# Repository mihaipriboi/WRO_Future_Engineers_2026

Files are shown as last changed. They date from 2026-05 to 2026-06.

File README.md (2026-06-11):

<center><h1> Nerdvana Cancer 2026 </center>

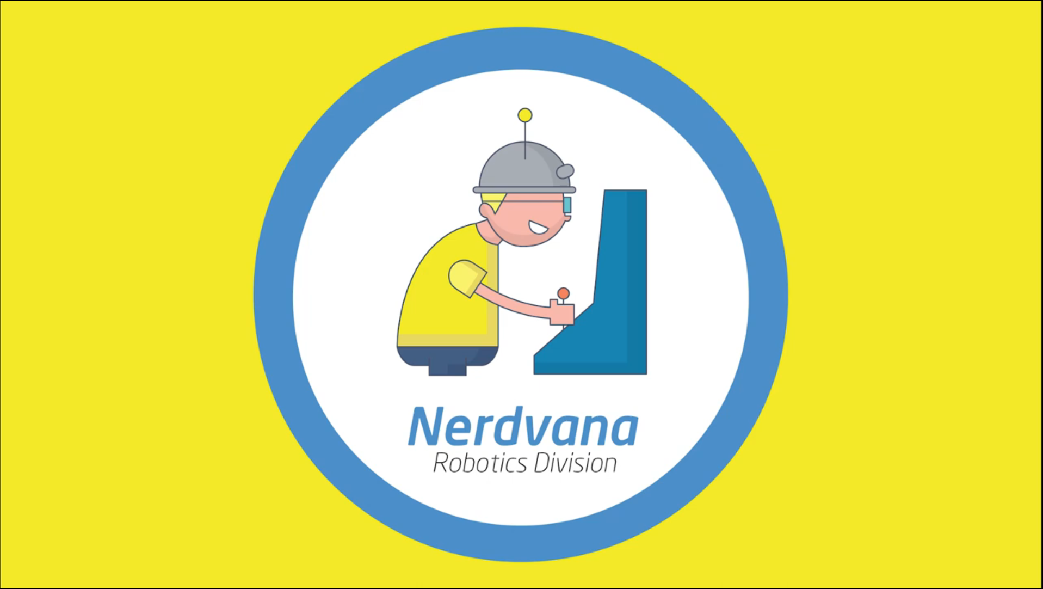
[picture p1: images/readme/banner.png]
Banner




This repository contains the documentation for the Nerdvana Cancer team's robot for the 2026 World Robot Olympiad Future Engineers competition. The robot, was designed and built by a team of three students.

## Table of Contents
* [The Team](#team)
* [The Challenge](#challenge)
* [The Robot](#robot-image)
* [Performance Video](#video)
* [The Team's Evolution Over the Years](#team-evolution)
  * [2022 Paula (Pretty Awesome Ultra Low Accurate robot) - International (Germany) - 8th Place](#2022-international)
  * [2023 Paula Mia (Pretty Awesome Ultra Low Accurate Minimum Intelligence Augmentation) - National - 1st Place](#2023-national)
  * [2023 Paula Mia 2 (Pretty Awesome Ultra Locomotion Autonomous Mapping Intelligence Augmentation) - International (Panama) - 17th Place](#2023-international)
  * [2024 TBD - National - 1st Place](#2024-national)
  * [2024 MOOYA (Mechanized Optimization for Outstanding Yield and Adaptation) - International (Turkey) - 7th Place](#2024-international)
  * [2025 MOOYA* (Mechanized Optimization for Outstanding Yield and Adaptation) - National - 1st Place](#2025-national)
  * [2025 L.A.C.H.E. (Lightweight Autonomous Carbon-Hybrid Entity) - International](#2025-international)
  * [2026 M.D.S (Memory, Dead-reckoning & Steering) - Current Robot](#2026-current)
* [Mobility Management](#mobility-management)
  * [Powertrain](#powertrain-mechanical)
    * [Drivetrain](#drivetrain-mechanical)
    * [Motor](#motor-mechanical)
    * [Motor Driver](#motor-driver-mechanical)
  * [Steering](#steering-mechanical)
    * [Servo Motor](#servo-motor)
  * [Chassis](#chassis-mechanical)
* [Power and Sense Management](#power-and-sense-management)
  * [Li-Po Battery](#li-po-battery)
  * [Arduino Nano ESP32](#arduino-nano-esp32)
  * [IMU](#imu-sensor)
  * [OpenMV Cam H7 R2](#openmv-cam-rt1062)
  * [Voltage Regulator](#voltage-regulator)
  * [PCB Design](#pcb)
  * [Circuit Diagram](#circuit-diagram)
* [Code for each component](#code-for-each-component)
  * [Drive Motor](#drive-motor-code)
  * [Servo Motor](#servo-motor-code)
  * [Camera](#camera-code)
  * [IMU](#gyro-sensor-code)
* [Obstacle Management](#obstacle-management)
  * [Qualification Round](#quali-management)
  * [Final Round](#final-management)
  * [Additional code](#additional-code)
* [What We Changed This Year](#whats-new)
  * [Tuning and telemetry over WiFi](#wifi-dashboard)
  * [A drift-free gyro that finds its own straight](#self-straight)
  * [Our own localization and route memory](#self-localization)
  * [Rethinking the parking](#smart-parking)
  * [Where this is heading](#next-steps)
* [Robot Construction Guide](#robot-construction-guide)
  * [Step 0: Print the 3D parts](#3d-printing)
  * [Step 1: Assemble the steering system](#steering-system-assembly)
  * [Step 2: Assemble the powertrain](#powertrain-assembly)
  * [Step 3: Attach the electronics](#electronics-attachment)
  * [Step 4: Upload the code](#code-upload)
* [Cost Report](#cost-report)
  * [3D Printing Costs](#3d-printing-costs)
  * [Other Parts Tested](#other-parts-tested)
  * [Tools and Equipment](#tools-and-equipment)
  * [Summary of Costs](#summary-of-costs)
* [Randomizer](#randomizer)
* [Resources](#resources)
  * [3D Models](#3d-models-resources)
  * [Images](#images-resources)
* [License](#copyright)

---

## The Team 

### Priboi Luca Mihai
<p align="center">
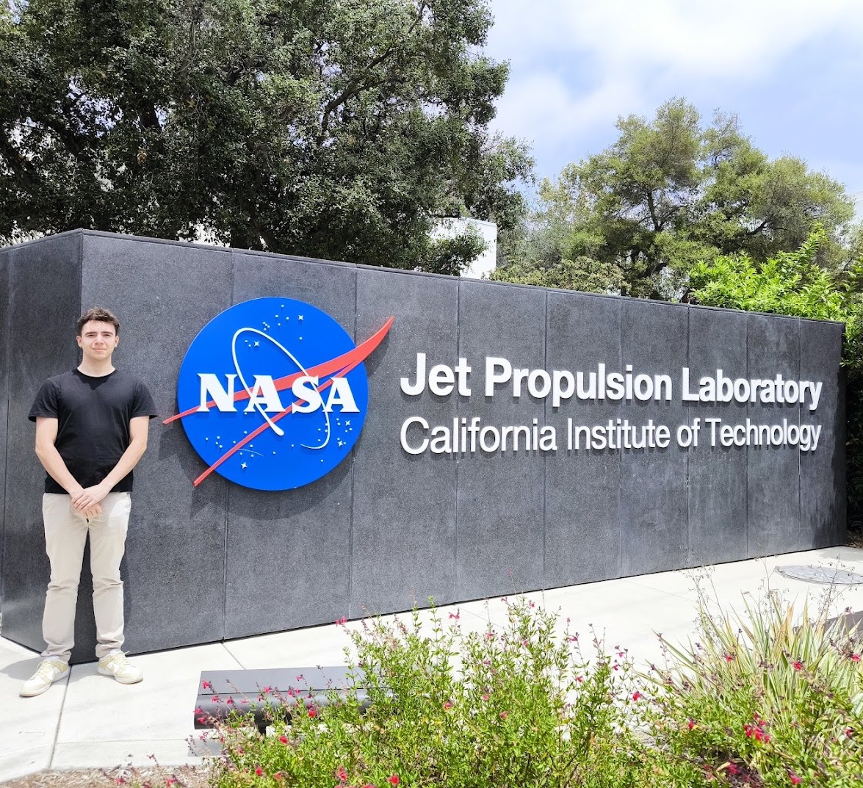
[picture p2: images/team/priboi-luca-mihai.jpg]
Priboi Luca Mihai
  
</p>

<b>Age:</b> 20

<b>University:</b> 2nd year, Politehnica University of Bucharest

<b>Description:</b> Hello! I am Mihai! I've been participating at WRO since 2015 and I am very excited to be part of the Nerdvana Romania team. My academic passions are programming, physics and robotics, but I also enjoy playing the piano 🎹, whatching movies 🎬, traveling ✈️ and Formula 1 🏎️🏁.

---

### Bălan Teodor Ovidiu
<p align="center">
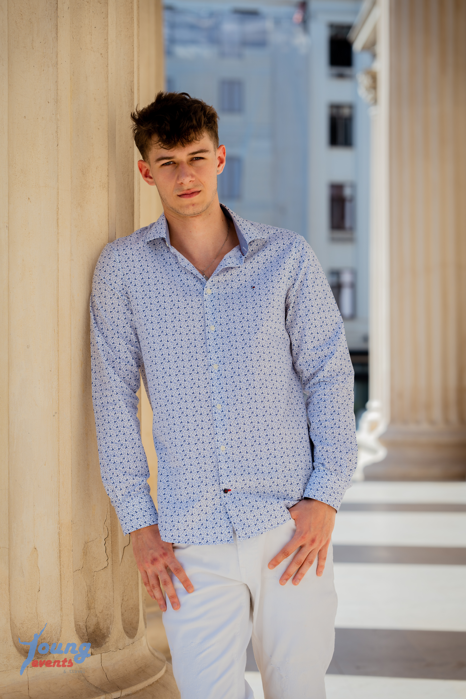
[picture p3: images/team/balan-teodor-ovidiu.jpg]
Bălan Teodor Ovidiu
  
</p>

<b>Age:</b> 20

<b>University:</b> 2nd year, University of Bucharest

<b>Description:</b> Wassup y'all! My name is Teodor, and I love traveling and experiencing new things. Since I was a kid, I've always been drawn to solving puzzles, playing basketball, discovering new inventions, and thinking of creative ways to do things. Also, I know how to do a backflip. 🤠

---

### Orășeanu Andrei
<p align="center">
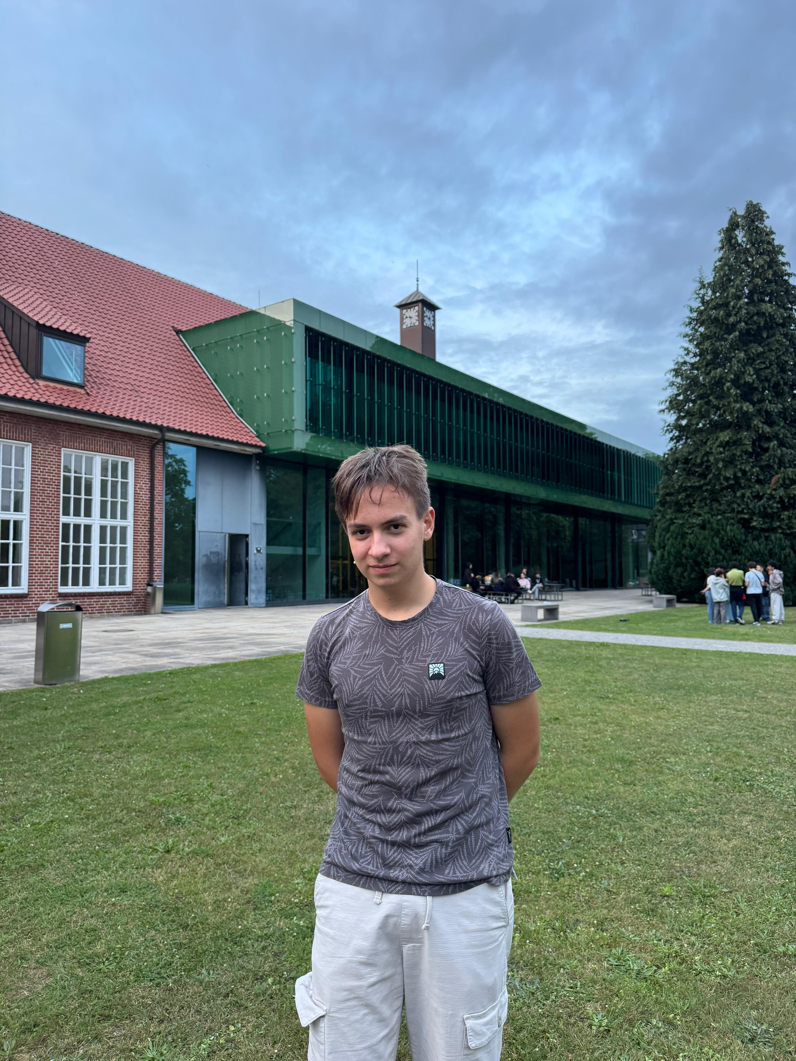
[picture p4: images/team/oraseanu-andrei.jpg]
Orășeanu Andrei
  
</p>

<b>Age:</b> 17

<b>School:</b> 11th grade, Colegiul Național Gheorghe Șincai

<b>Description:</b> Hello! I'm Andrei, and I've been part of WRO since 2023. What pulled me in from the very first season was the part where you build something with your own hands and then have to teach it to think for itself, that moment when the robot finally does the thing on its own never gets old. My main passions are robotics and physics, but outside the workshop I love traveling ✈️, a long game of chess ♟️, and playing basketball 🏀. I joined the team this year wanting to push our self-driving car further than we ever have, and so far it's been exactly the kind of challenge I was hoping for.

---

### Priboi Maria Marcela
<p align="center">
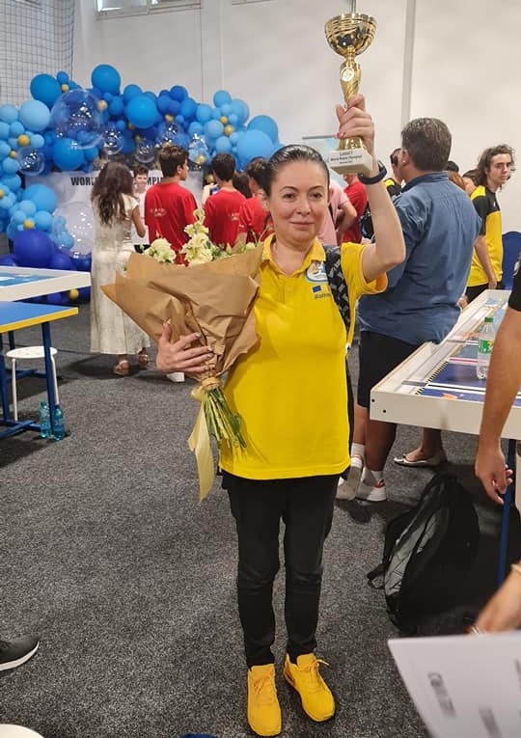
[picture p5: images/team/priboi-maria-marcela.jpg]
Priboi Maria Marcela
  
  <p align="center">Nerdvana Romania Founder</p>
</p>

<b>Role:</b> Coach

<b>Description:</b> I am a very ambitious person, I like to work hard and to be involved in many projects. I am a very organized person and I like to have everything planned. I am a very sociable person and I like to communicate with people. I am a very responsible person and I like to take care of everything that is happening around me. I am a very creative person and I like to come up with new ideas. I am a very determined person and I like to achieve my goals.

## The Challenge 

The **[WRO 2026 Future Engineers - Self-Driving Cars](https://wro-association.org/)** challenge invites teams to design, build, and program a robotic vehicle capable of driving autonomously on a racetrack that changes dynamically for each round. The competition includes two main tasks: completing laps while navigating randomized obstacles and successfully performing a precise parallel parking maneuver. Teams must integrate advanced robotics concepts such as computer vision, sensor fusion, and kinematics, focusing on innovation and reliability.

This challenge emphasizes all aspects of the engineering process, including:
- **Mobility Management:** Developing efficient vehicle movement mechanisms.
- **Obstacle Handling:** Strategizing to detect and navigate traffic signs (red and green markers) within specified rules.
- **Documentation:** Showcasing engineering progress, design decisions, and open-source collaboration through a public GitHub repository.

Points are awarded based on performance in the challenge rounds, quality of the engineering documentation, and the ability to create an innovative and robust solution. The goal is to inspire STEM learning through real-world robotics applications, teamwork, and creative problem-solving.

Learn more about the challenge [here](https://wro-association.org/wp-content/uploads/WRO-2026-Future-Engineers-Self-Driving-Cars-General-Rules.pdf).

## Photos of our robot M.D.S (the proven L.A.C.H.E. chassis) 

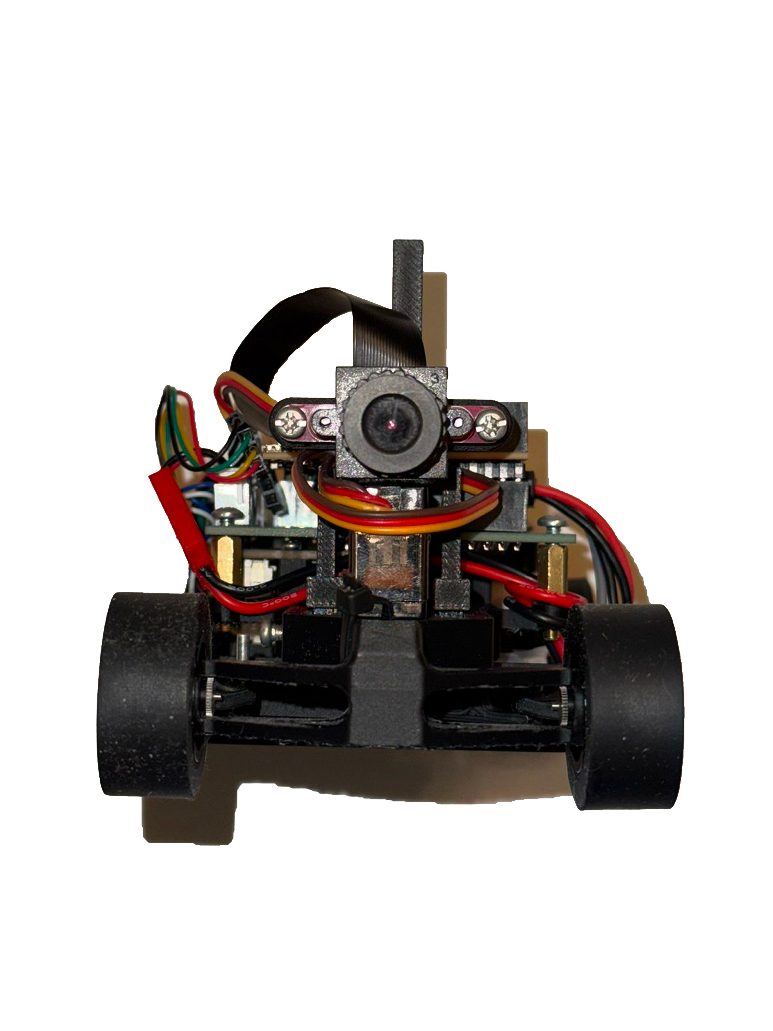
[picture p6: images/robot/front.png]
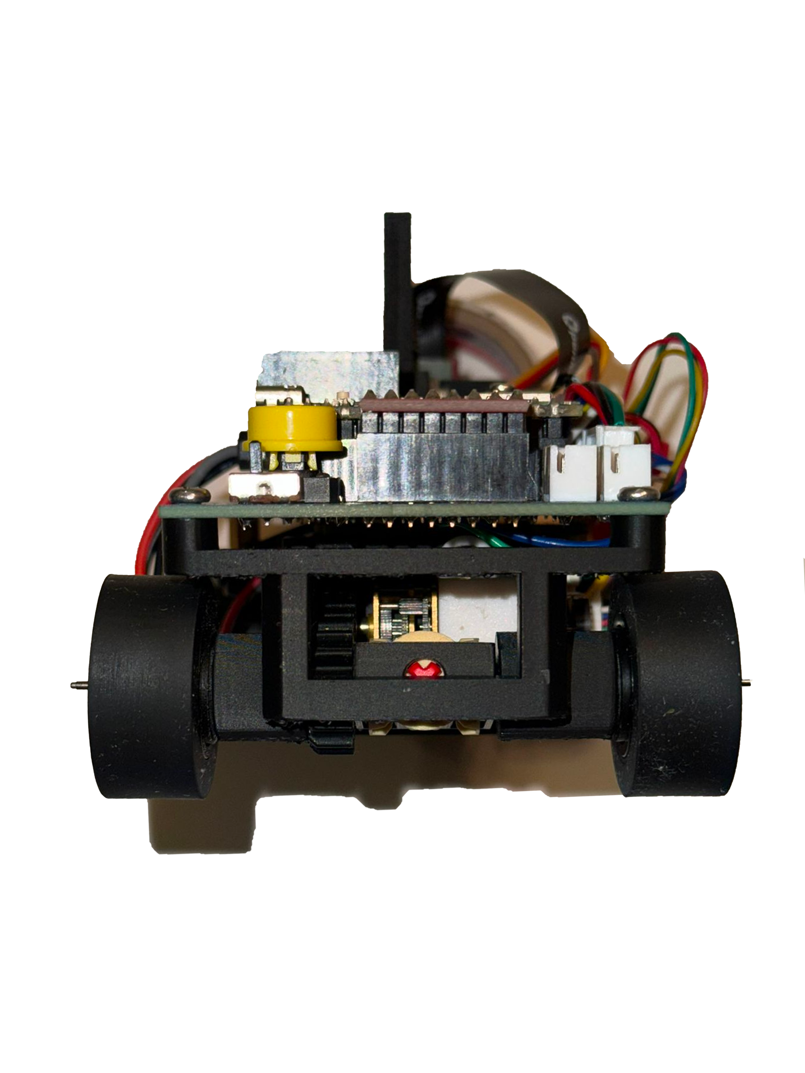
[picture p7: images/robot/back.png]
|  |  | 
| :--: | :--: |
| *Front* | *Back* |
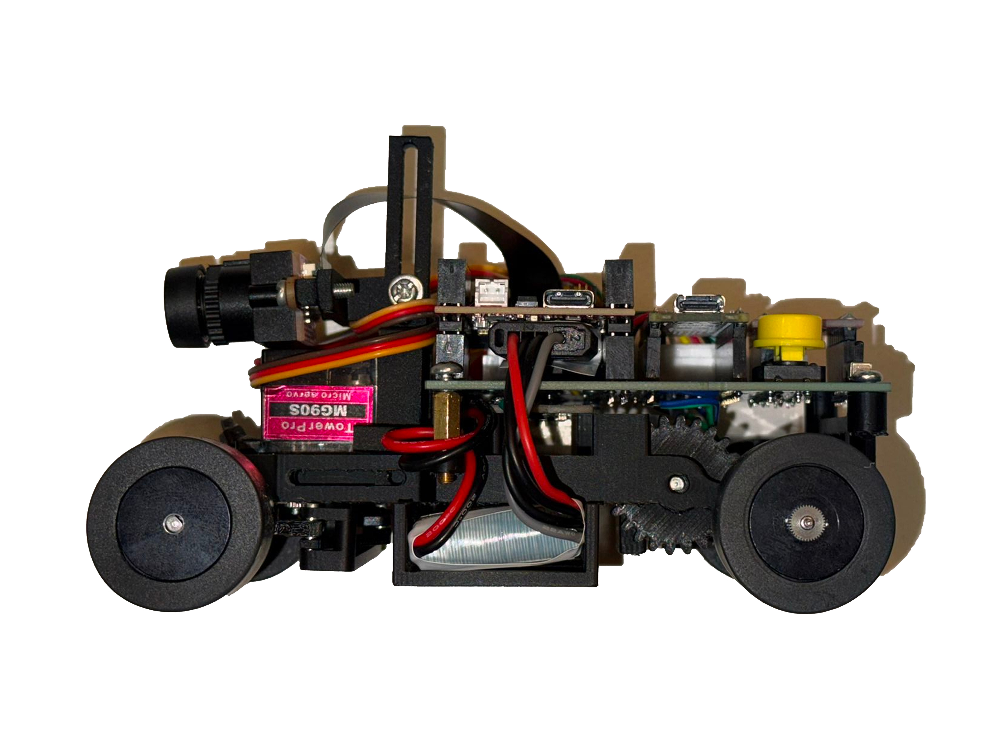
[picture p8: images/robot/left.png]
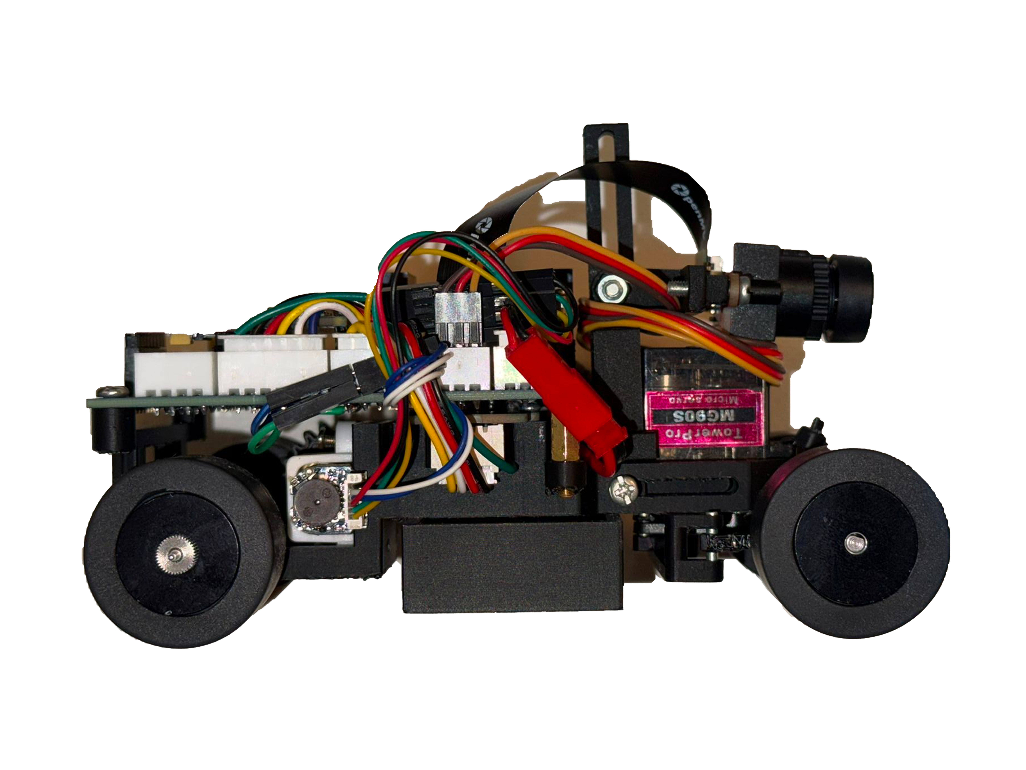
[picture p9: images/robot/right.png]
|  |  | 
| *Left* | *Right* |
|  |  | 
| *Top* | *Bottom* |

<br>

## Our video of the robot on [Youtube](https://www.youtube.com/watch?v=aLT0-nPUaAE) 

<br>

# Our Team's Evolution Over the Years 

We have been participating in the Future Engineers category since 2022, the first year it was introduced in Romania. While our team has seen some changes in membership over the years, we have consistently worked together to build on our experiences. Throughout this time, we have grown and evolved, both in our skills and in our approach to robotics, developing increasingly sophisticated strategies and designs with each competition.

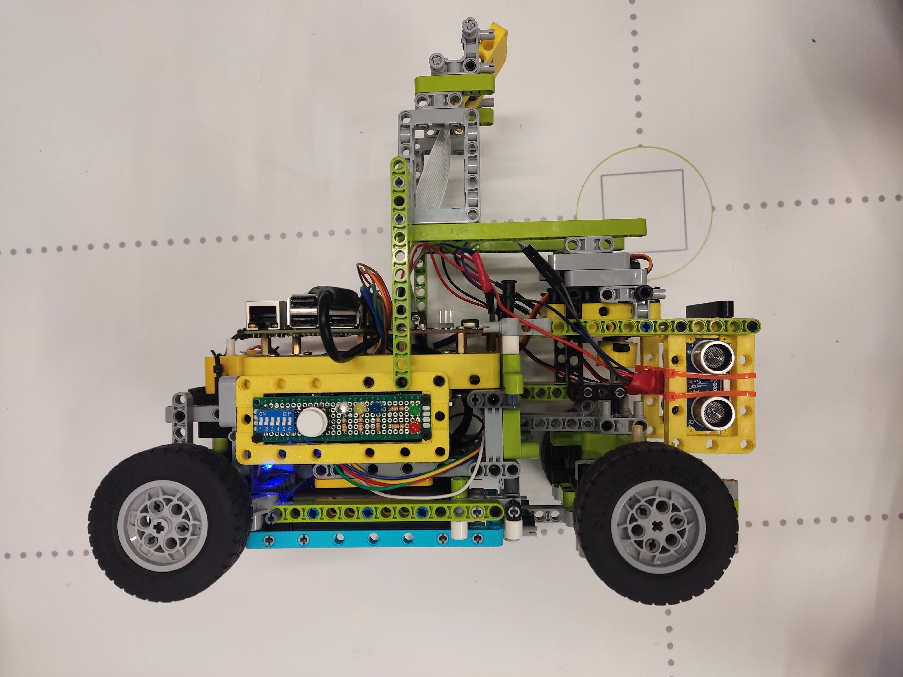
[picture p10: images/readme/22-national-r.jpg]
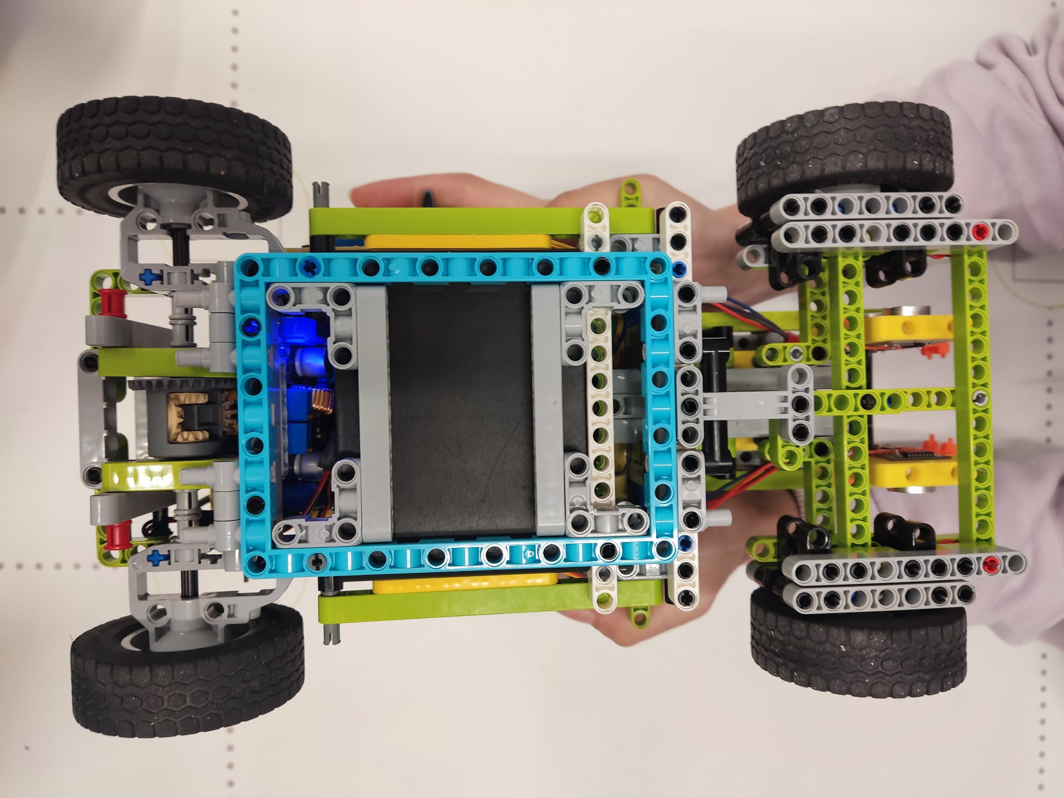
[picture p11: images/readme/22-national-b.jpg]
|  |  |
| :--: | :--: |
| *2022 National Competition* |
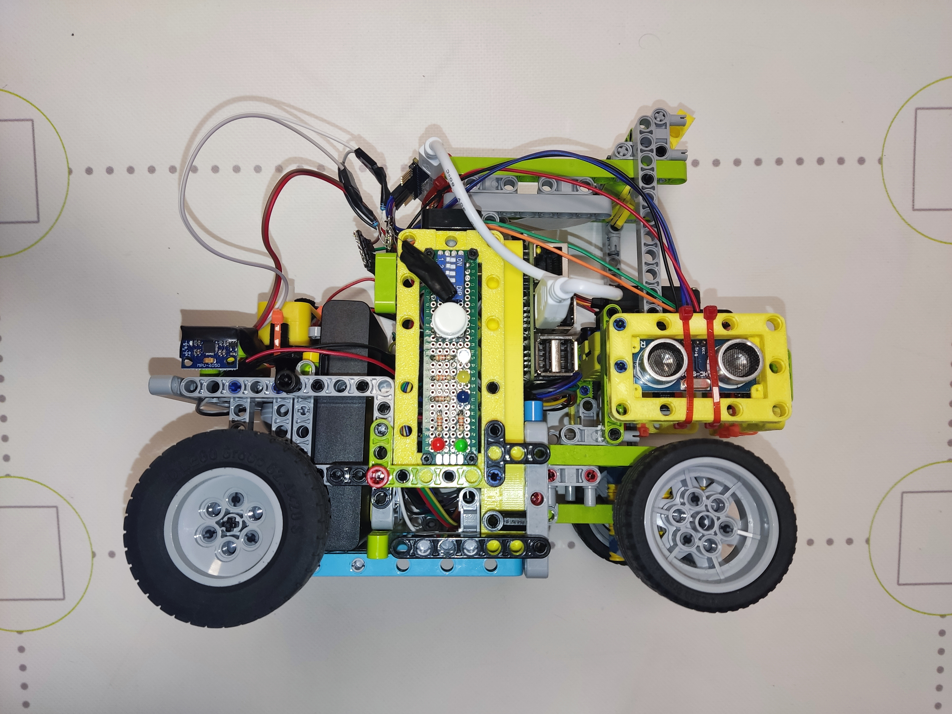
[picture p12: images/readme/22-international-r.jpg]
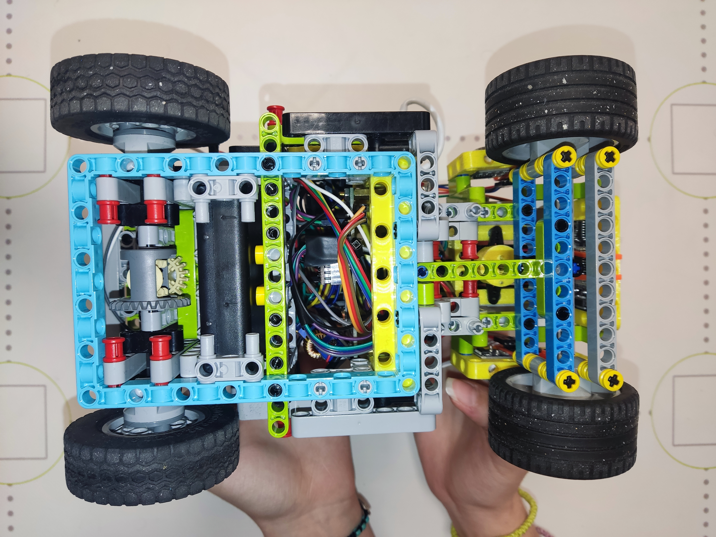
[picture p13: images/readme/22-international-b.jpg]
|  |  |
| *2022 International Competition* |
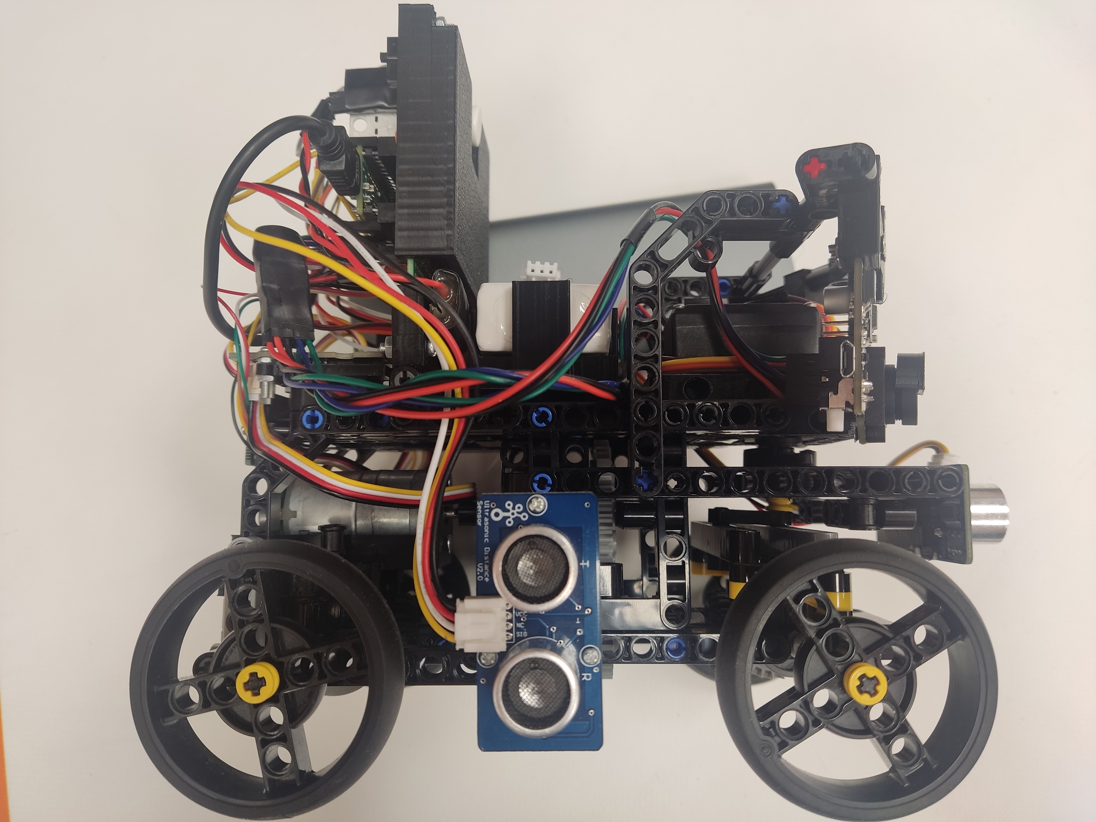
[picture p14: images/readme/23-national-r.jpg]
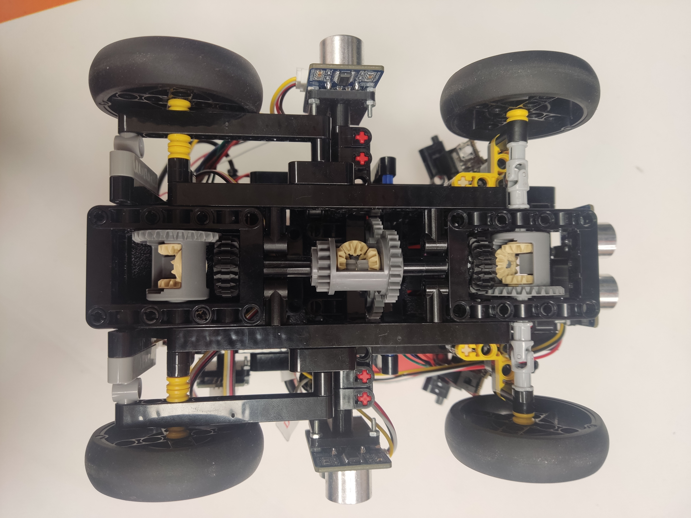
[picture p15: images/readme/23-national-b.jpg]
|  |  |
| *2023 National Competition* |
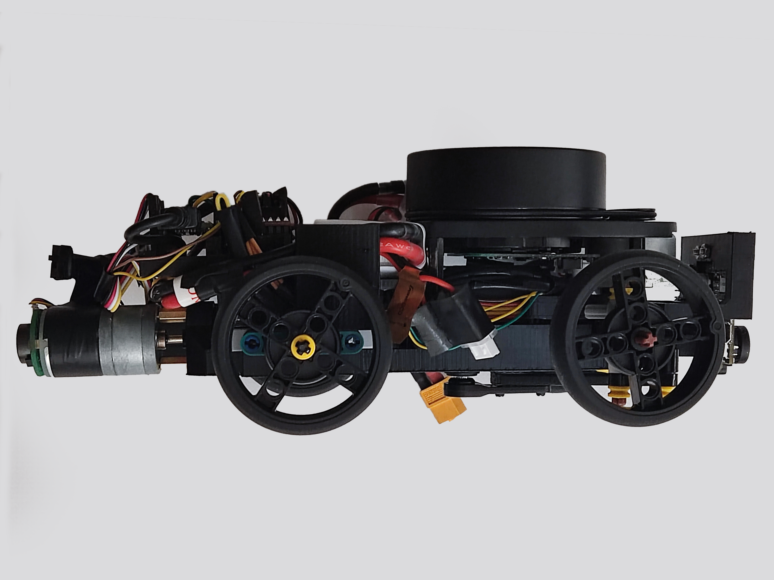
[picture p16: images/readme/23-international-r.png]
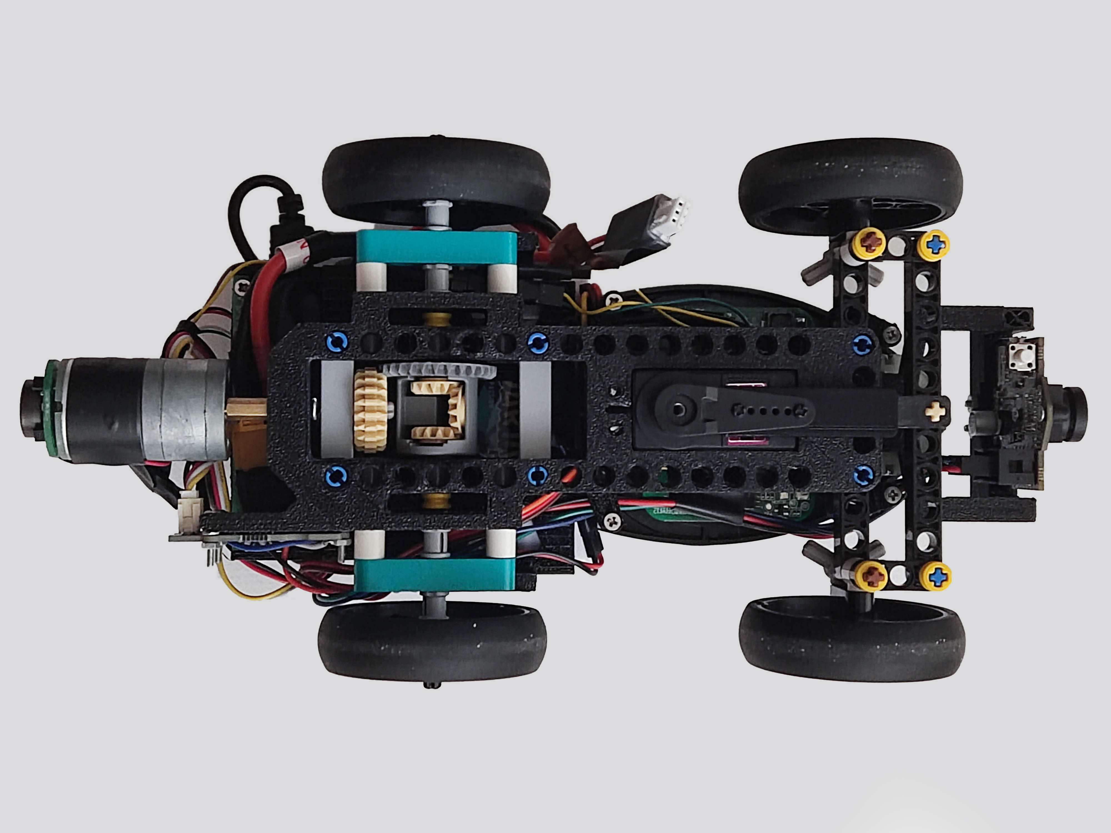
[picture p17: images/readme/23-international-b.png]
|  |  |
| *2023 International Competition* |
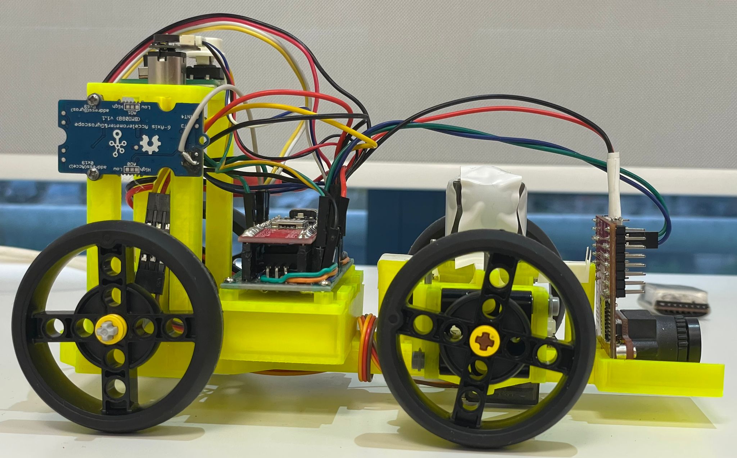
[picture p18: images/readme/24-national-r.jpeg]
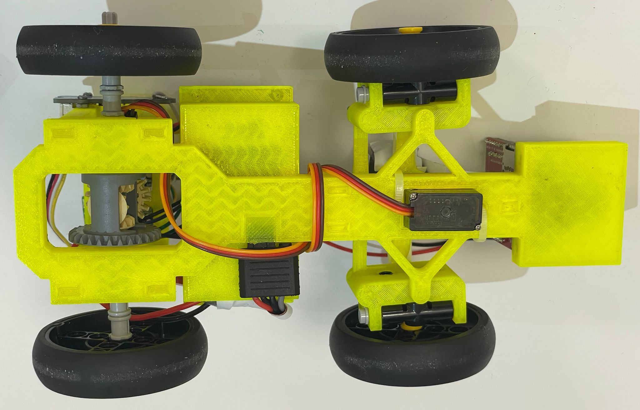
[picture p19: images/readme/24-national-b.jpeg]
|  |  |
| *2024 National Competition* |
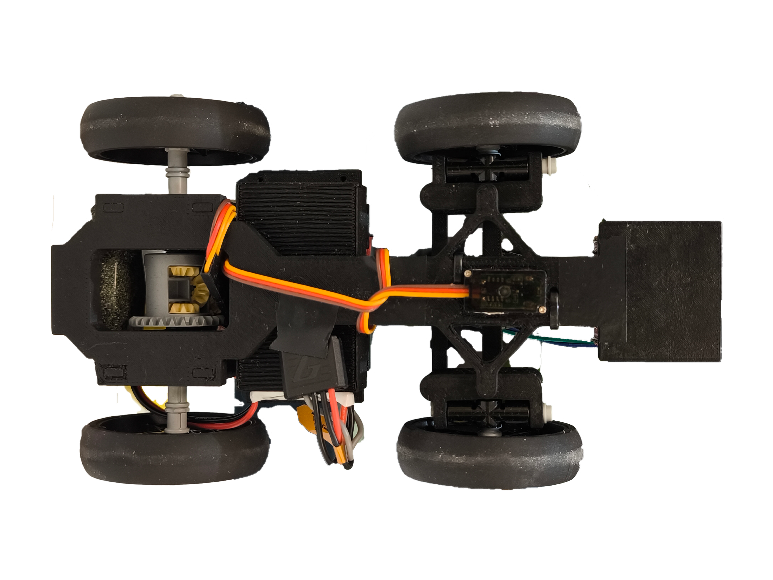
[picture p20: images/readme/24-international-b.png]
|  |  |
| *2024 International Competition* |
|  |  |
| *2025 National Competition* |
|  |  |
| *2025 International Competition* |
|  |  |
| *2026 Season — same chassis, new software (M.D.S)* |

## 2022 (No Name) - National - 1st Place 
Our first robot, built for the 2022 Future Engineers competition, was a large, bulky, and mostly Lego-based design, building on our previous experience with RobotMission (which was exclusively Lego Mindstorms). We experimented with adding more advanced components, including a Raspberry Pi 3 with a Pi Camera for object detection, a non-Lego motor and servo, and an Arduino to handle the electronics interface. The Raspberry Pi and Arduino communicated through a custom handshake, and we added ultrasonic sensors for wall and object detection.

3D printing was used minimally, mainly to hold components in place, with some parts even “floating” on cables. Cabling was improvised, using standard-length mother-to-mother wires without much organization. Power was supplied by a small battery pack holding six AAA rechargeable cells. Overall, it was a beginner-level robot: heavy, slow, and cumbersome, with limited processing power and a program that was challenging to run efficiently. At this stage, it did not yet have a name, unlike our later tradition of giving each robot an identity.

## 2022 Paula (Pretty Awesome Ultra Low Accurate robot) - International (Germany) - 8th Place 
The idea was mostly the same as our first robot: a Lego-heavy build, but much sturdier than the flimsy predecessor. Electronics were upgraded with a faster Arduino Nano Every, and we added another ultrasonic sensor at the front for wall detection going forward, along with a bigger, stronger servo. The steering system was still imprecise, the motor remained slow, and cables were everywhere (classic “spaghetti style”).

Perhaps the biggest change was the addition of an MPU6050 gyro, which significantly improved driving straight and performing precise maneuvers, a component we would keep in our designs going forward (though we later found even better options).

Despite the imperfections, with a lot of hard work, some fair bit of luck, and sheer motivation, we managed to rank 8th place. Looking back, as we would see in the following year, the other teams were just as inexperienced, but learning quickly, a reminder that Future Engineers is as much about growth as competition.

## 2023 Paula Mia (Pretty Awesome Ultra Low Accurate Minimum Intelligence Augmentation) - National - 1st Place 
This robot was a major tipping point for us. The base and powertrain were still Lego, but nothing like before. They were rigid, smaller, and efficient, using only what was necessary. Mechanically, this is probably my favorite robot, and the most distinct one.

We implemented an AWD system with three differentials (front, back, and a middle differential actuated directly by the motor), which was bigger, more powerful, and faster than before. The camera was upgraded to a PixyCam, removing the need for the Raspberry Pi and allowing the Arduino to handle the input from the trained camera. Crucially, we added two cameras at angles, giving us large coverage of the map.

Electrically, this was a huge leap. We moved from messy cables everywhere to a prototyping board that organized all components, with dedicated, custom-made cables to reach detached components. We also added small but useful features: a display to see data when not connected to a laptop, and a LiPo battery (larger capacity, higher voltage, lighter, smaller, and easily swappable).

Steering angle was still quite bad, and the code was complicated, messy, and hardly consistent, but the AWD system solved a major issue of losing power in turns. We also upgraded the gyro to a BMI088, which we still use today. Overall, smaller than before but still not tiny, this robot showed a significant evolution in mechanical design, electronics, and vision, laying the foundation for our future builds.

## 2023 Paula Mia 2 (Pretty Awesome Ultra Locomotion Autonomous Mapping Intelligence Augmentation) - International (Panama) - 17th Place 
This robot brought major changes to our design. The frame was now fully 3D-printed, replacing the big, flexible Lego structure with a monocoque that was lighter, stiffer, and more compact. However, the wheels, differential, and steering system were still Lego, as printing such small components proved too brittle, introduced friction, and reduced precision (not that Lego is precise anyway).

We experimented with a 360° LiDAR, which in theory allowed us to see all walls and obstacles from any angle at any time. Our main programmer, Teo, wrote brilliant code for detecting them consistently and efficiently. The large LiDAR and its height limitations forced compromises: no AWD system this time, as fitting it alongside the LiDAR was impossible. We also reduced to a single camera, relying on the LiDAR for obstacle detection while the camera captured object color and position for tracking.

Electronics were upgraded to a much faster Teensy microcontroller, offering frequencies magnitudes higher than the Arduino Nano Every. This came with compatibility challenges and sparse documentation, but we managed to make it work. Cable management finally improved, though some wires were still visible. Steering precision improved, but not dramatically.

Going to Panama, we were confident, but color calibration issues due to lighting differences affected performance. The robot was inconsistent, and we managed the situation worse than we could have, resulting in 17th place. Meanwhile, other teams had advanced significantly with brilliant solutions we hadn't considered.

Despite the setback, this experience reinforced the essence of Future Engineers: learning, communicating, and sharing knowledge. We gained as much as we could, returned home, and immediately started designing a new, better robot, determined to surpass everything we had built before.

## 2024 TBD - National - 1st Place 
Oops! We decided to hold off on naming our best robot yet, which resulted in forgetting to give it a proper name at the national competition :). This robot represented the culmination of everything we had learned over the previous two long (at least it felt like it) years in Future Engineers.

Design and mechanics: Lego was minimal, just for mounting the big wheels (which we had been using for a while and saw no reason to change) and the differential (still for friction reasons). Everything else was 3D-printed, modular, and lightweight, made from translucent yellow PLA, our club color. It followed the trend: smaller, lighter, faster, and fully visible, no hidden parts, random Lego pieces, oversized LiDARs, or messy cables.

Electronics and control: We returned to Arduino for better documentation and integration (though that model had firmware issues and could break easily. One could hope!). The microcontroller was an Arduino ESP32 Nano, providing speed and wireless programming capabilities (though we ended up sticking with wired uploading due to web app limitations).

Vision and sensing: We upgraded from the PixyCam to an OpenMV camera, programmable in Python, supporting object detection with machine learning, fine-tuned resolution, FPS, and exposure settings. Distance from cubes and walls was now derived directly from the camera, eliminating the need for distance sensors.

Steering and performance: We built a custom parallelogram steering system, simple but effective. But, with large wheels, a faster motor, and reduced weight, high-speed corners caused the front wheels to skid. To solve this, we added weights over the front of the body, improving friction and stability.

This robot combined all the lessons from past competitions: modularity, lightness, precision, speed, and simplicity. It was the first design where everything we wanted actually came together, setting the stage for our international competition robot later that year.

## 2024 MOOYA (Mechanized Optimization for Outstanding Yield and Adaptation) - International (Turkey) - 7th Place 
This was the same base as our previous national robot (finally with a proper name), with the focus shifting mostly to code refinement. We worked on making the program as efficient and reliable as possible, but mechanical challenges persisted.

Despite being quite light (~300 g), the robot still skidded in high-speed corners. To counteract this, we added weights over the front wheels to improve grip, which caused the rear to lift during acceleration. Adding rear weight again shifted the problem to the front: a vicious cycle. Ultimately, the robot reached almost 600 g, and we also switched to PLA-CF filament (PLA with carbon fibers) for increased strength, which helped the thin steering pieces survive the competition.

Performance at Istanbul ranked us 7th place. It wasn't our highest potential, and while saying we were "disappointed" might be too strong, we were definitely not fully satisfied. Skidding, imprecise steering, and camera issues from auto-exposure and other settings prevented us from performing as well as in testing. This experience highlighted exactly what we needed to focus on for the next edition: minimizing skidding, improving steering precision, and resolving camera reliability issues.

## 2025 MOOYA* (Mechanized Optimization for Outstanding Yield and Adaptation) - National - 1st Place 
For the national competition, we used the same robot with targeted upgrades. The OpenMV camera was replaced with a newer, more powerful model, offering higher resolution, faster FPS, and additional options for object detection. Its microcontroller was upgraded as well, improving processing speed and reliability.

With these changes, we were confident that previous camera issues would be resolved. Other mechanical and design aspects remained the same, allowing us to focus on fine-tuning and testing while simultaneously developing the next-generation robot. This strategy ensured we could maximize performance at the national level while preparing for the next step in our evolution.

## 2025 L.A.C.H.E. (Lightweight Autonomous Carbon-Hybrid Entity) - International 
Following the trend of evolution, our current robot is smaller, faster, more precise, and highly custom-made. Every aspect of the design reflects lessons learned from previous years.

Mechanical design:
- Fully 3D-printed drivetrain and frame using PLA-CF for strength and rigidity.
- Smaller Pololu wheels, chosen for better adherence, lower center of gravity, and compact size.
- Differential and minimal Lego parts retained only where friction made it advantageous.
- Total weight: 220 g, achieving excellent speed without any skidding.

Electronics:
- Designed a custom PCB, replacing previous prototyping boards and making the system more integrated and reliable.
- Custom cables with snap-in headers ensure correct orientation and prevent shorts or miswiring (no more accidental mistakes like in earlier designs).
- The camera is detached and easily repositionable along all axes (horizontal, vertical, and rotation) within seconds, avoiding hours of redesign like before.
- Microcontroller and wiring optimized for minimal weight and maximum performance.

Performance:
- Lightweight and compact, yet mechanically robust.
- Steering and drivetrain tuned for high-speed precision, eliminating skidding problems from previous robots.
- The robot's modularity allows for quick component swaps and adjustments.

This robot represents the culmination of four years of experience: compact, fast, lightweight, and precise. With improved electronics, optimized mechanics, and programmable vision, it's now up to us to make the best of it in the next competitions.

## 2026 M.D.S (Memory, Dead-reckoning & Steering) - Current Robot 
This season we did something we'd never done before: we left the robot alone. L.A.C.H.E. was the first build where the mechanics genuinely weren't the thing holding us back, the drivetrain is smooth, the Ackermann steering is precise, the weight sits where we want it, so re-printing the whole thing just to say we changed something felt like fixing what wasn't broken. Every robot photo in this repository is still that exact chassis, and the construction guide below still builds it part for part.

What changed is the part you can't really photograph. This year's car is L.A.C.H.E.'s body running a completely reworked brain, and that's the reason it earns its own name. **M.D.S** stands for the three ideas that brain is built around: **M**emory, we record the line we drive so we can replay a good lap instead of reacting to every corner from scratch; **D**ead-reckoning, the robot now tracks its own position on the mat from the gyro and the encoder; and **S**teering, the car calibrates its own dead-straight trim from real driving data instead of us dialing it in by hand. It also fits the challenge nicely, a self-driving car that drives from memory and knows where it stands.

All of it is written up in detail in [What We Changed This Year](#whats-new): a drift-free 1000 Hz gyro, a steering center the robot finds on its own, live tuning over WiFi, and the start of our own on-board localization. The short version is that the hardware is the same proven L.A.C.H.E., and the whole of this season went into teaching it to actually know where it is and to drive a line it has already learned.

# Mobility Management 

The robot's mobility is managed by a combination of components, including the powertrain, steering system, and chassis. These elements work together to ensure the robot's smooth and efficient movement.

## Powertrain 

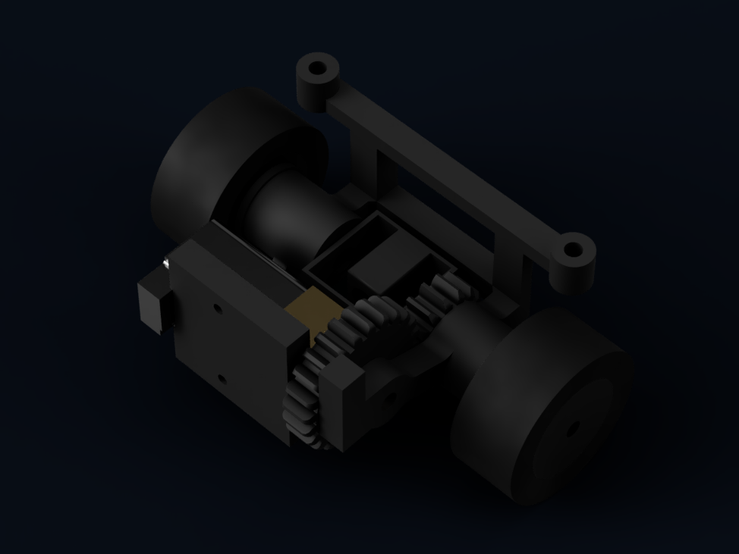
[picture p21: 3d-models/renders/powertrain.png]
Powertrain


Between the motor and the wheels, there is a 1:2 gear ratio drivetrain that increases the speed of the robot while reducing the torque. This setup allows the robot to reach higher speeds on the track, which is essential for completing laps quickly. It's made by using a 24 teeth gear connected to the motor axle, which drives a 12 teeth gear attached to the differential input axle.

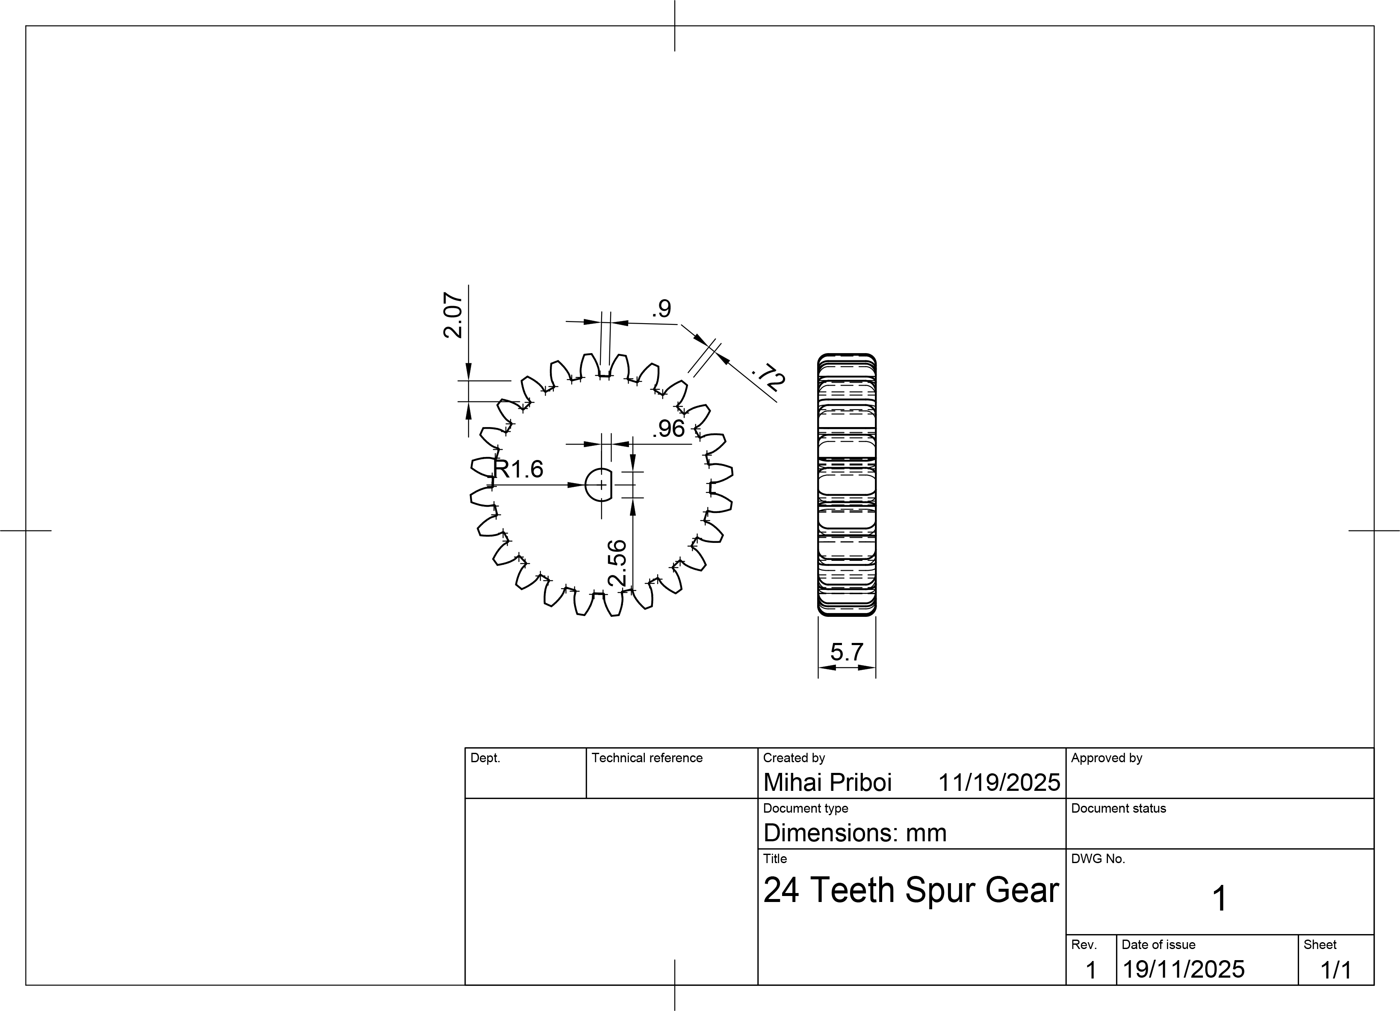
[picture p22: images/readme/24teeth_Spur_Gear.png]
24 Teeth Spur Gear - 3D Model 24 Teeth Spur Gear 3D piece


For the differential we used the work of @COPERNICON_359779 on printables.com https://www.printables.com/model/344703-lego-micro-diff-compact-modular-design/files under Creative Commons - Public Domain.

### Drivetrain 
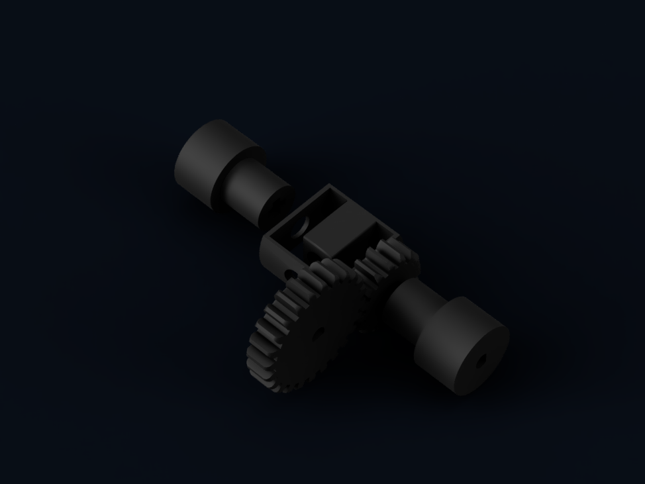
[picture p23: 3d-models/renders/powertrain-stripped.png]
Powertrain Stripped


To minimize friction and maximize speed, the drivetrain combines the best of our previous Lego experience with a fully custom, precision-controlled layout. Although most structural elements are now 3D-printed, we still use two Lego axles, but only to connect with the three small internal gears of our custom 3D-printed differential. This keeps the extremely low friction and reliability of Lego's small internal gears while allowing the outer housing, tolerances, and geometry to be fully customized.

Because we transitioned to Pololu wheels, we designed a custom connector that converts the Lego axle interface to a 3 mm D-shaft, ensuring a perfectly centered, secure fit. This allowed us to retain the low-friction Lego internal gear system while benefiting from the superior grip, reduced weight, and lower rotational inertia of Pololu wheels.

The entire drivetrain is tightly enclosed inside the chassis, which was designed around it with minimal clearance. This enclosure reduces backlash, eliminates unnecessary play, and guarantees consistent alignment of the gears and axles. Every internal sliding surface is sanded, bringing friction down to nearly zero and allowing the robot to maintain high speed without compromises in stability or precision.

The result is our most efficient drivetrain yet, compact, lightweight, smooth, and engineered to take full advantage of every bit of power the motor provides.

<br>

**Potential Improvements**:
- Upgrade to a more precise metal differential for smoother turning, which would also remove the need for Lego axles.

### Motor 

<table>
  <tr>
    <td width="50%" style="text-align: left;">
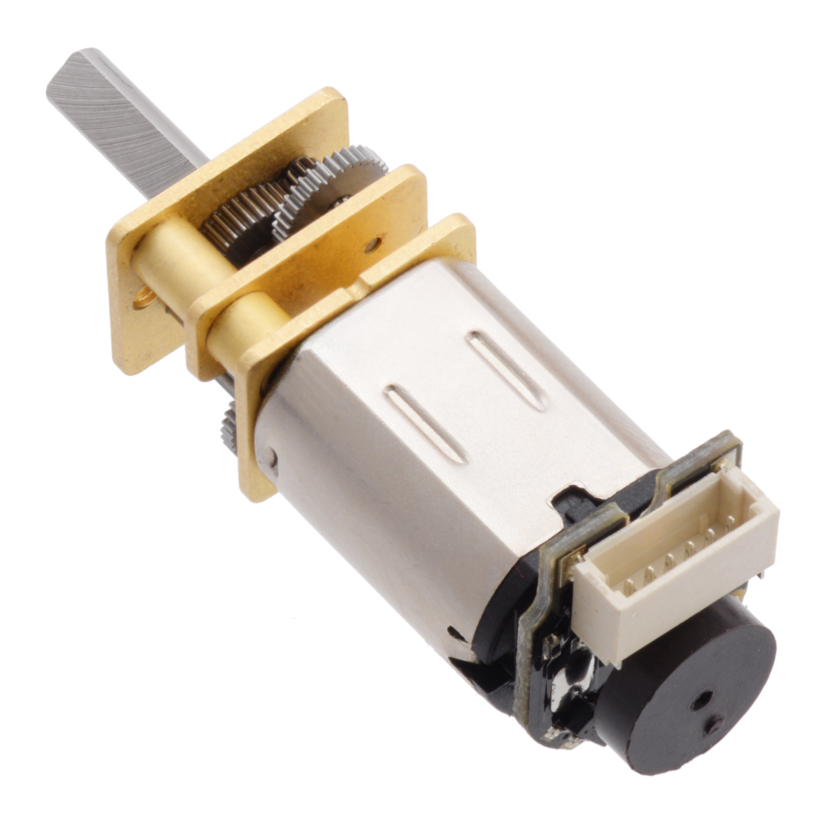
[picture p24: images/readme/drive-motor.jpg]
DC Gearmotor
      
    </td>
    <td width="50%" style="text-align: left; vertical-align: top;">
      <h3>Specifications:</h3>
      <li>Voltage: 12V</li>
      <li>Gear Ratio: 30:1</li>
      <li>Speed: 1100 ± 31% rpm</li>
      <li>Torque: 0.39 ± kg·cm</li>
      <li>Weight: 9.5g</li>
      </li>
    </td>
  </tr>
</table>

Following an evaluation of different motors, we settled on a micro DC gear motor on which we attached a magnetic encoder. This motor was selected for its lightweight and compact design, which stands out among others with comparable output. Additionally, the magnetic encoder offers greater precision than its optical counterpart. We secured the motor to the chassis using a Pololu white plastic mounting bracket. As for the wheels, we used Solarbotics RW2i Wheel (internal set screw), which are 28mm diameter wheels with a 3mm D-shaft, rubber tread, and 12.7mm width, which provides excellent traction on the competition surface.

<table>
  <tr>
    <td width="33%" style="text-align: left;">
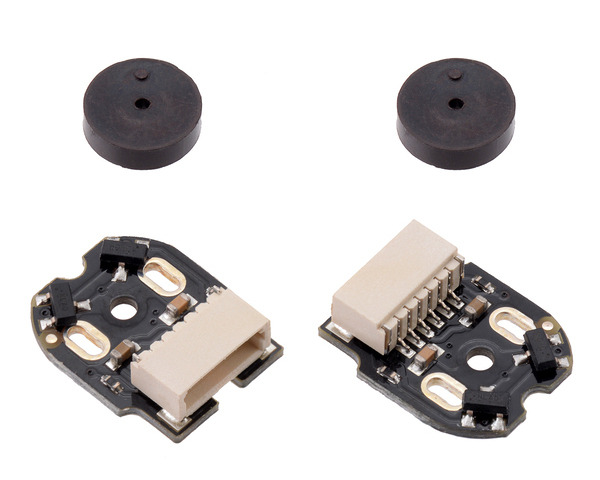
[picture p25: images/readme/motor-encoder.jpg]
Motor bracket
      
    </td>
    <td width="33%" style="text-align: left; vertical-align: top;">
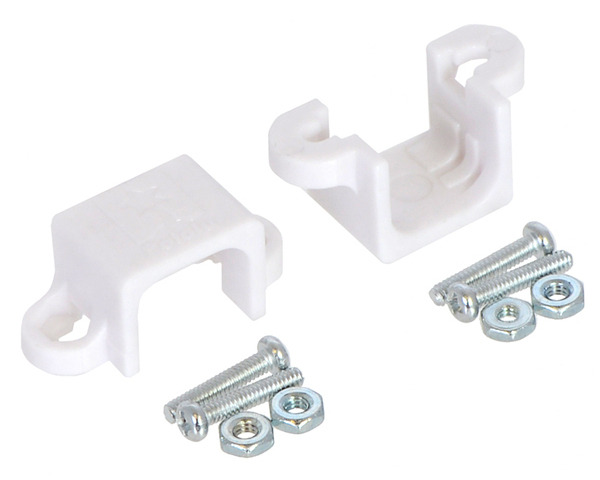
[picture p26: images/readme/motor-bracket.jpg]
Motor bracket
      
    </td>
    <td width="33%" style="text-align: left; vertical-align: top;">
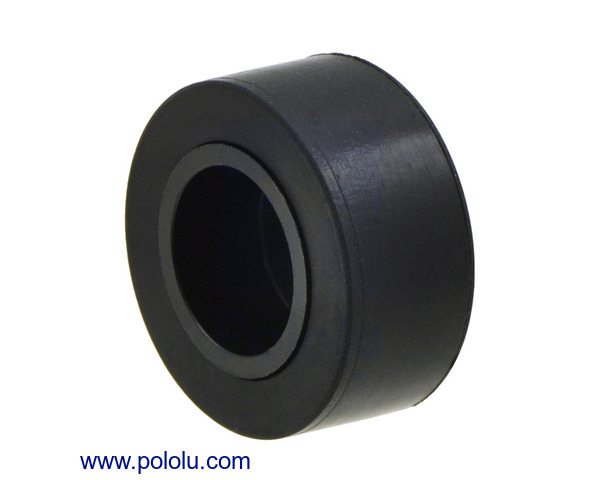
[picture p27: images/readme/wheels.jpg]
wheels
      
  </tr>
</table>

Where to buy the motor: https://www.pololu.com/product/3039
Where to buy the encoder: https://www.pololu.com/product/4761
Were to buy the motor bracket: https://www.pololu.com/product/1086
Where to buy the wheels: https://www.tme.eu/ro/details/pololu-1127/accesorii-pentru-robotica-si-rc/pololu/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

<br>

**Potential Improvements**:
- Consider upgrading to a brushless motor for higher efficiency and better thermal management.
- Explore batery solutions that can provide higher voltage to the motor for increased speed and torque.

### Motor Driver 

<table>
  <tr>
    <td width="50%" style="text-align: left;">
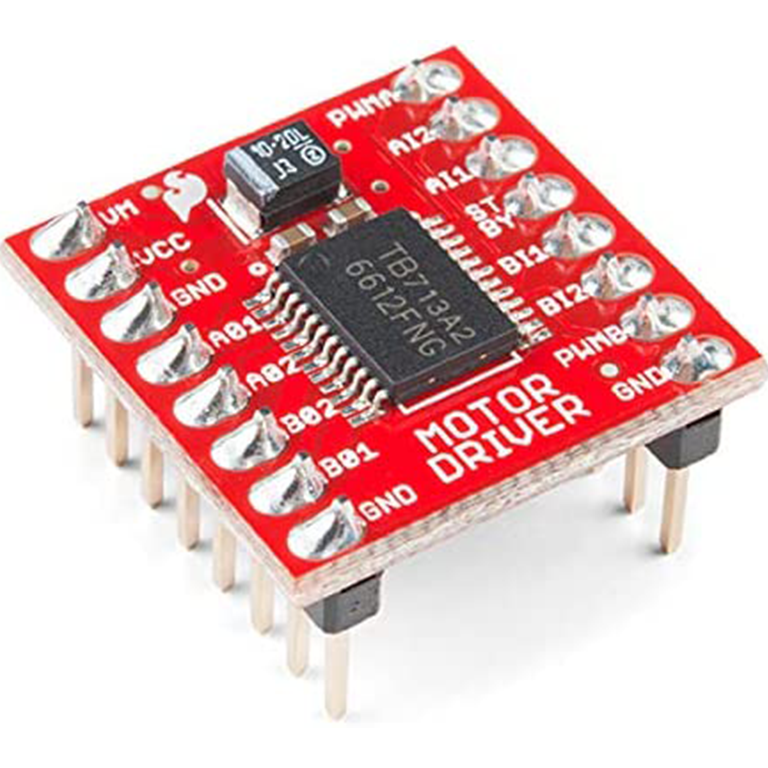
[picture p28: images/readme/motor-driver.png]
Motor driver
      
    </td>
    <td width="50%" style="text-align: left; vertical-align: top;">
      <h3>Specifications:</h3>
      <li>Power supply voltage: VM = 15V max, VCC = 2.7--5.5V</li>
      <li>Output current: Iout = 1.2A (average) / 3.2A (peak)</li>
      <li>Standby control to save power</li>
      <li>CW/CCW/short-brake/stop motor control modes</li>
      <li>Built-in thermal shutdown circuit and low-voltage detecting circuit</li>
    </td>
  </tr>
</table>

To control the speed of the drive motor, we utilized a SparkFun Dual TB6612FNG motor driver.

Where to buy the motor driver: https://www.sparkfun.com/products/14450

<br>

**Potential Improvements**:
- Replace the motor driver with a custom PCB to reduce weight and improve space utilization.
- Add active cooling or heat sinks for enhanced thermal performance during extended use.
- Explore higher-current motor drivers to accommodate potential motor upgrades.
- Implement a more robust power management system to ensure reliable operation.

## Steering 

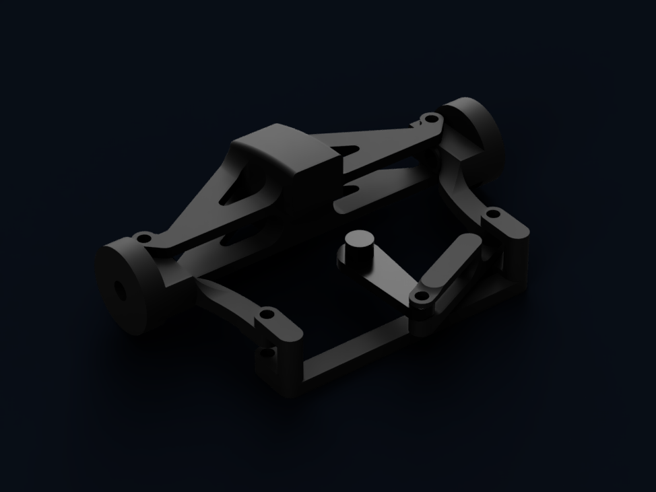
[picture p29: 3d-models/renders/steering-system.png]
Steering System


For this robot, we completely redesigned the steering system, moving away from the older parallelogram linkage and finally implementing a true Ackermann steering geometry. This upgrade allows the wheels to follow natural turning arcs, reducing slip during cornering and providing far more predictable handling at high speeds.

A major structural improvement is that the pivot point is now located inside the wheel itself, rather than outside as in previous designs. This drastically increases steering rigidity, improves response time, and eliminates a large portion of the unwanted flex that affected earlier robots.

The joints use 2 mm steel rods, which provide excellent strength-to-weight ratio and near-zero play. However, we changed the geometry of the steering linkages:
the distance between the steering pivot and the tie-rod mounting point is now significantly larger. This was done intentionally to reduce the influence of servo backlash and any free movement in the servo arms. The longer lever arm means that any tiny servo play translates into much smaller unwanted wheel rotation—greatly improving precision, especially when driving straight or making micro-adjustments.

The steering knuckles, tie rod and steering column are all custom 3D-printed and tightly integrated into the chassis. The compact design reduces weight, while the enclosed mounting ensures consistent alignment and minimal lateral movement.

Overall, this is our most precise, responsive, and stable steering system to date: lighter, smoother, and far more accurate than any previous generation.

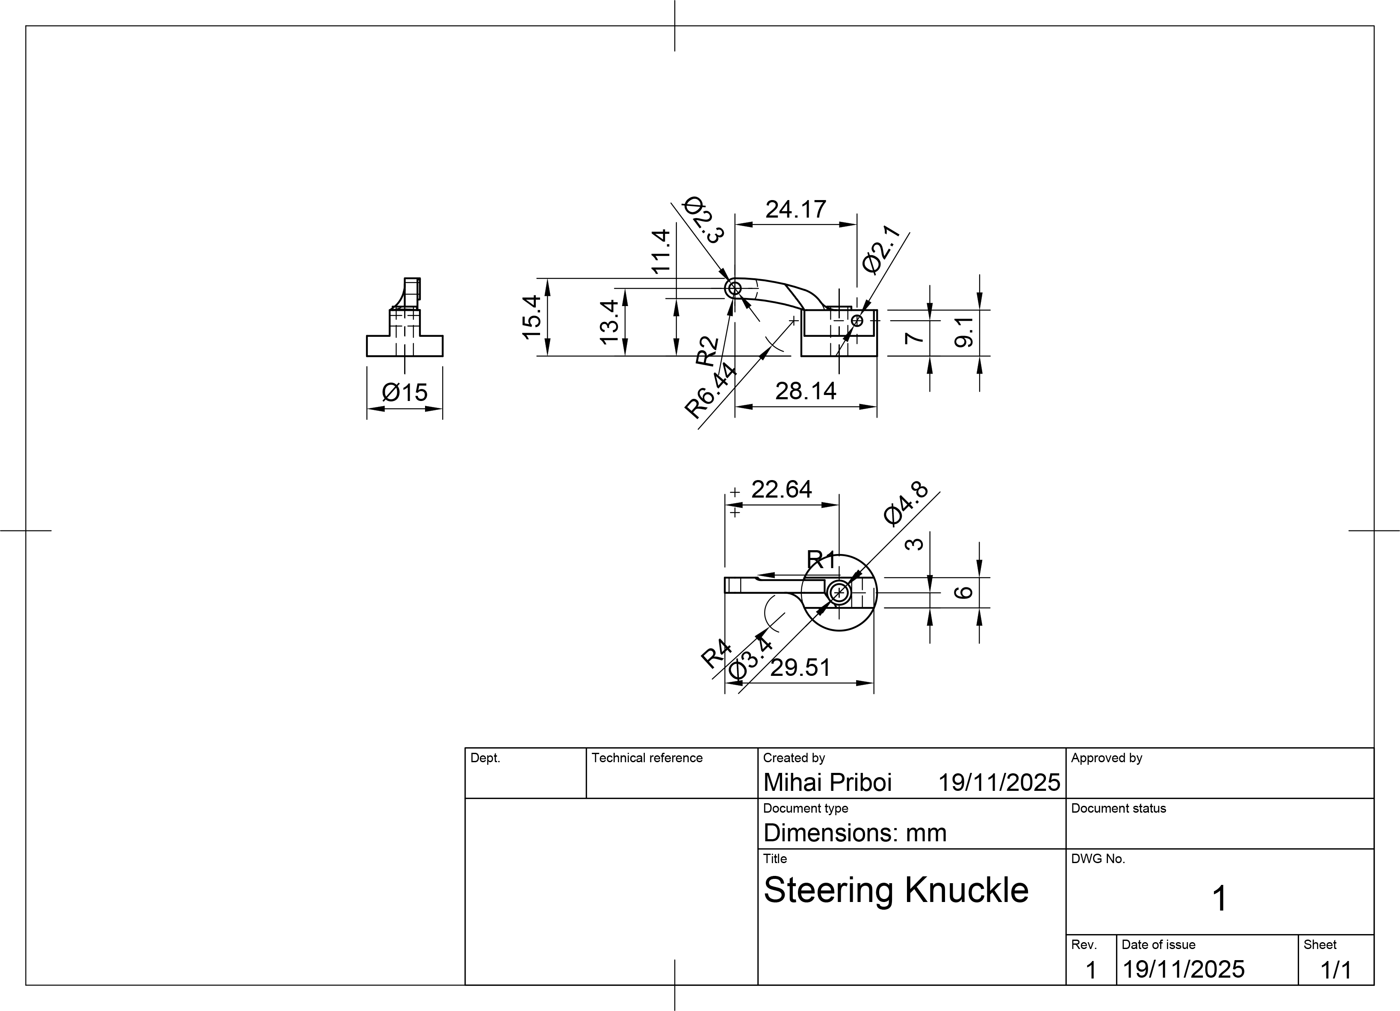
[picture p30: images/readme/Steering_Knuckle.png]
Steering Knuckle


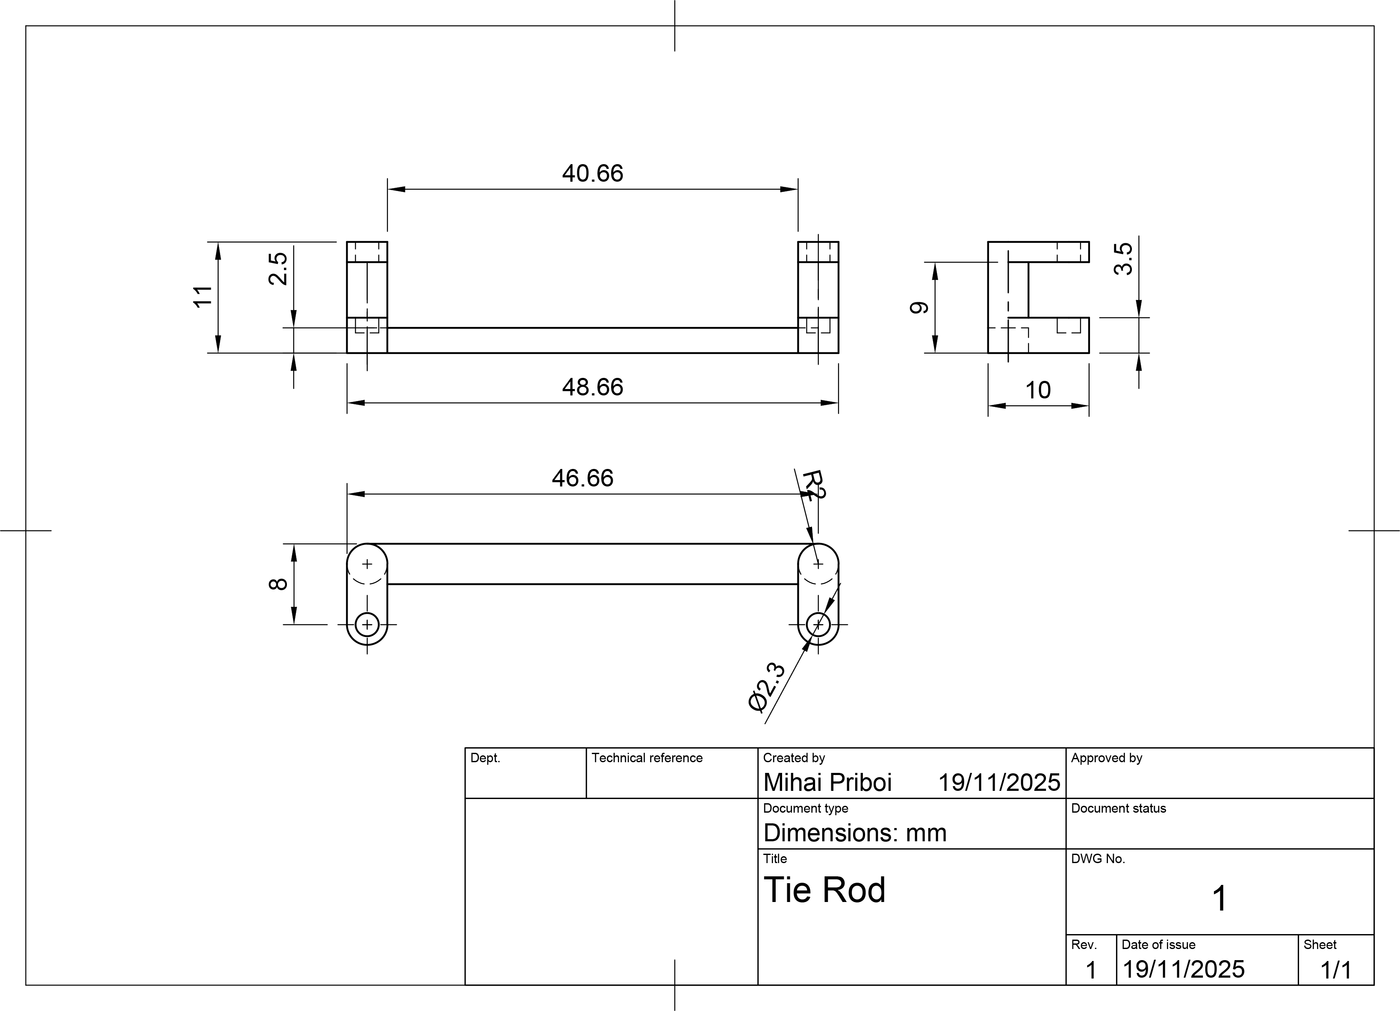
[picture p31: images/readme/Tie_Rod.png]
Tie Rod


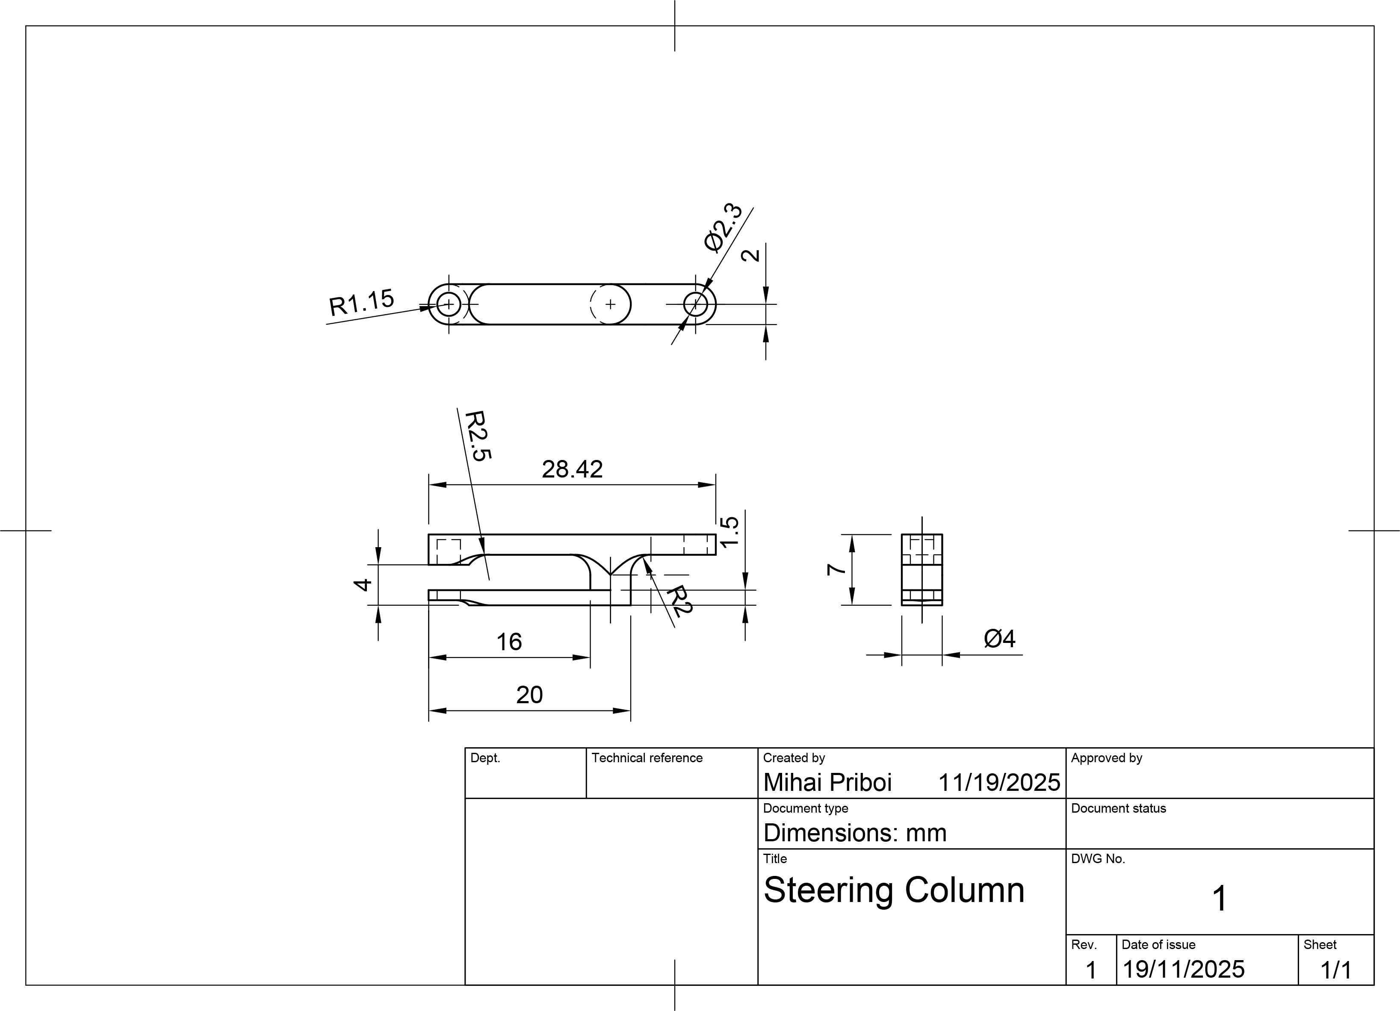
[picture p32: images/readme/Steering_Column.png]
Steering Column


<br>

**Potential Improvements**:
- Make the steering angle wider to improve the robot's turning radius.
- Use ball-bearing joints in the linkage to reduce friction and increase durability.
- Replace the 3D-printed components with lightweight aluminum for greater strength.

### Servo Motor 

<table>
  <tr>
    <td width="50%" style="text-align: left;">
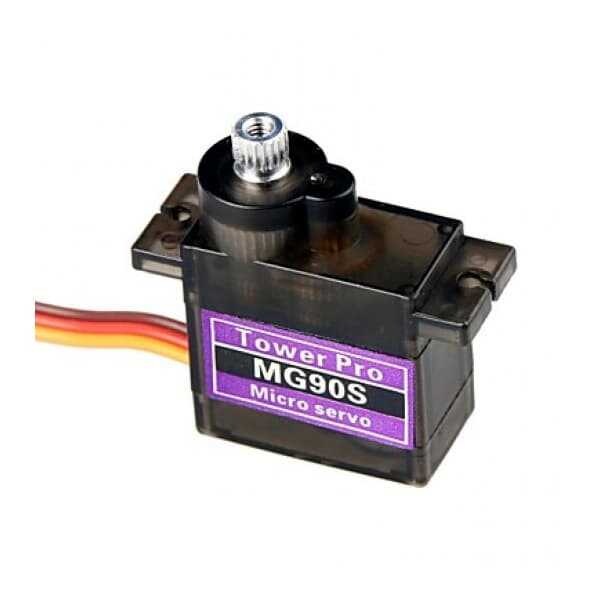
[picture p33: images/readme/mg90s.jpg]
Servo Motor
      
    </td>
    <td width="50%" style="text-align: left; vertical-align: top;">
      <h3>Specifications:</h3>
      <li>Weight: 13.4g</li>
      <li>Stall torque: 2.2 kgf·cm (6V)</li>
      <li>Operating speed: 0.08 s/60 degree (6V)</li>
      <li>Rotation angle: 120 degree</li>
    </td>
  </tr>
</table>

For steering, we selected the MG90S servo motor, favoring it for its high torque and swift response.

Where to buy the servo motor: https://cleste.ro/motor-servo-mg90s-180g.html

<br>

**Potential Improvements**:
- Test servos with a wider rotation angle to improve steering flexibility.
- Integrate position feedback into the servo for real-time adjustment and enhanced precision.

## Chassis 

Over the years, our robots transitioned from bulky, Lego-dominated builds to increasingly custom and lightweight designs. This year, the chassis is now almost entirely 3D-printed, built with PLA-CF (carbon-fiber–reinforced PLA). This material choice drastically improves stiffness, reduces flex under load, and provides far better durability than traditional PLA, especially for thin steering components and structural mounts.

By redesigning every subsystem with minimalism in mind and reducing the number of individual parts, the robot became approximately 50% lighter than last year's version while also being significantly smaller and more compact. This size reduction improves handling, center of gravity, and serviceability.

The entire chassis is tightly integrated so that all drivetrain, steering, and electronic components sit securely with minimal backlash or unwanted movement.

The chassis is organized into clear functional zones:

**Rear Section:** Houses the new custom 3D-printed differential, tightly enclosed to reduce vibrations and friction.

**Central Section:** Contains a dedicated cutout for the Li-Po battery, above which the gyro is screwed in. The custom PCB is mounted above that, screwed into the chassis as well. The compact layout ensures short signal paths and extremely clean cable management.

**Front Section:** Holds the servo motor, steering assembly, and the now movable camera bracket. The camera is mounted on an adjustable multi-axis bracket, allowing quick repositioning in seconds (a task that previously required major redesigns).

Overall, this year's chassis reflects a philosophy of precision, compactness, and complete customization. Every feature, from material choice to structural layout, was designed to minimize weight, reduce friction, and maximize performance.

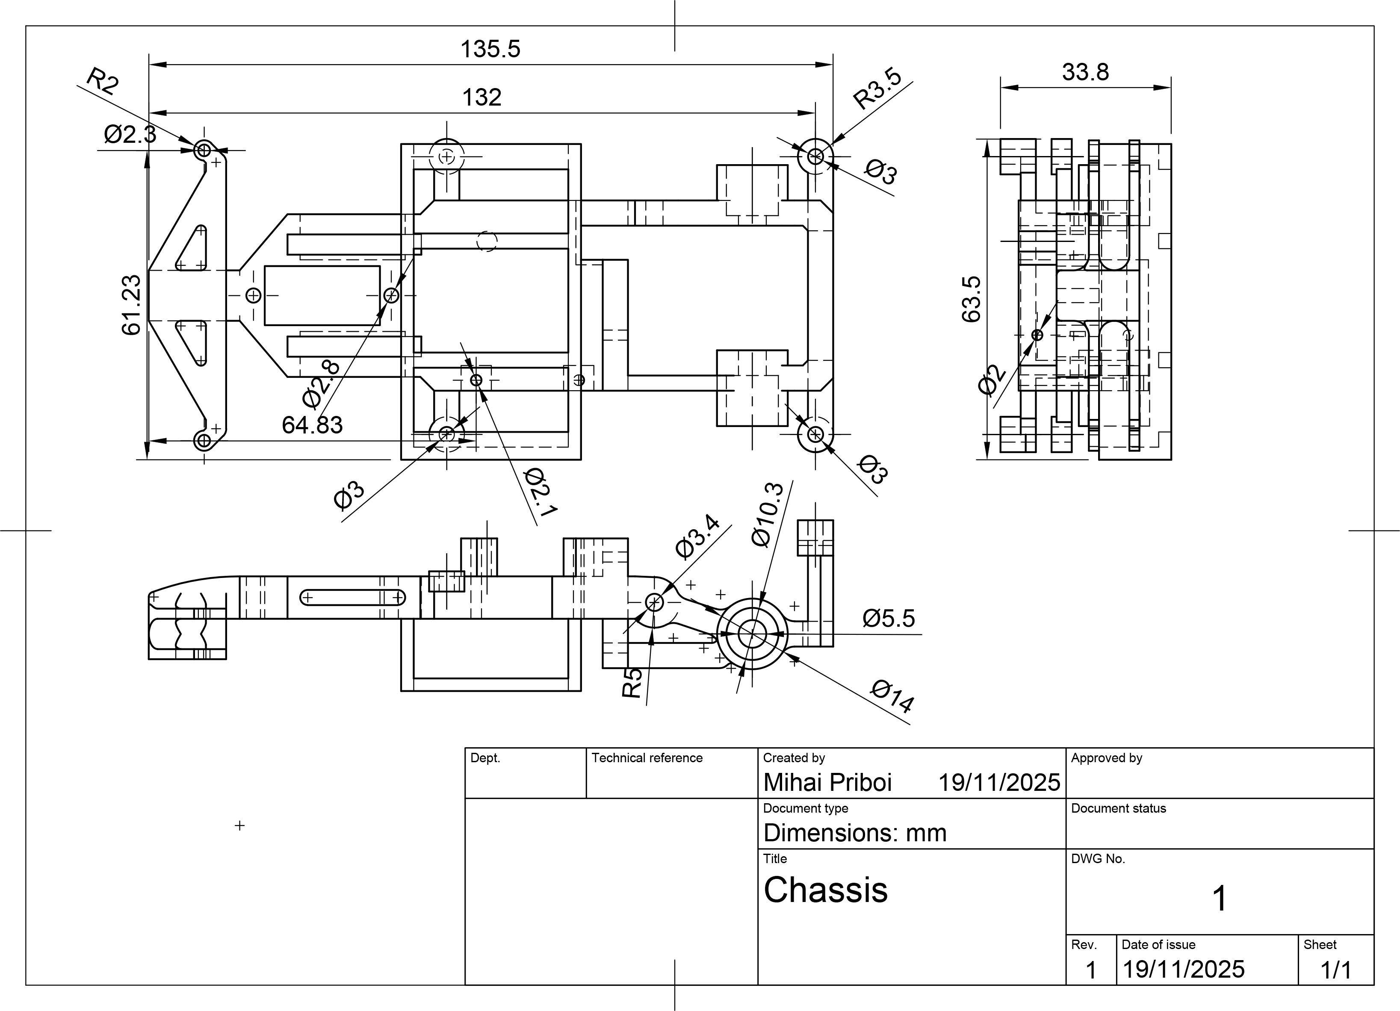
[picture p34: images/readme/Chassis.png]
Chassis


The Camera Mount is designed to be adjustable along the horizontal axis. It screws into the chassis.

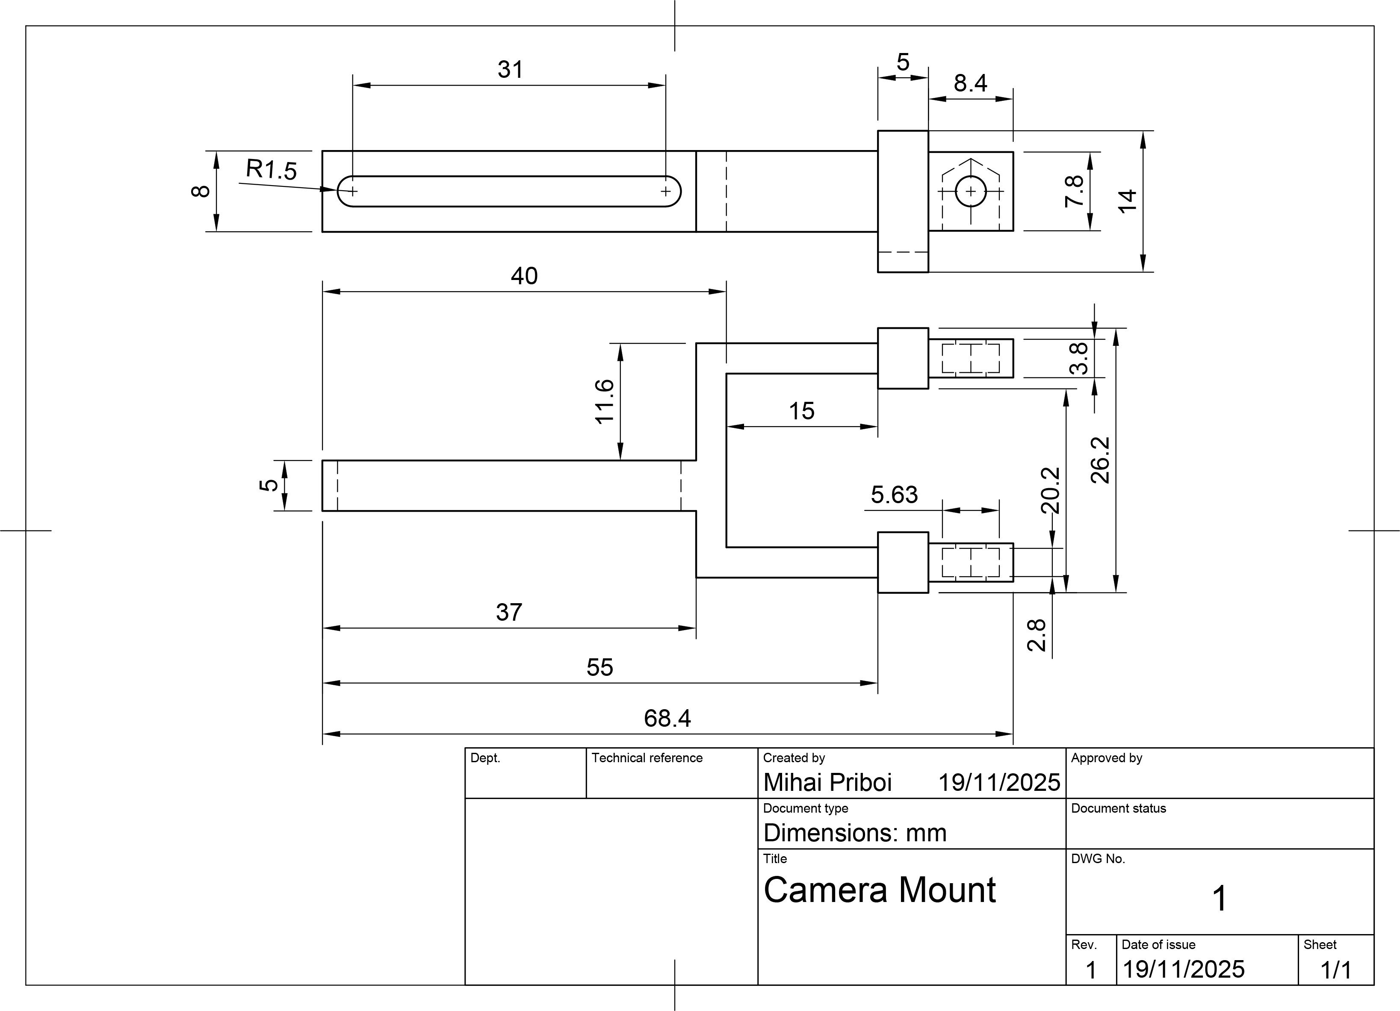
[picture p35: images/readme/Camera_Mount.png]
Camera Mount


The Camera Bracket is designed to be adjustable along the vertical axis and to rotate. It screws into the Camera Mount. The OpenMV Camera lens is attached to the Camera Bracket using screws.

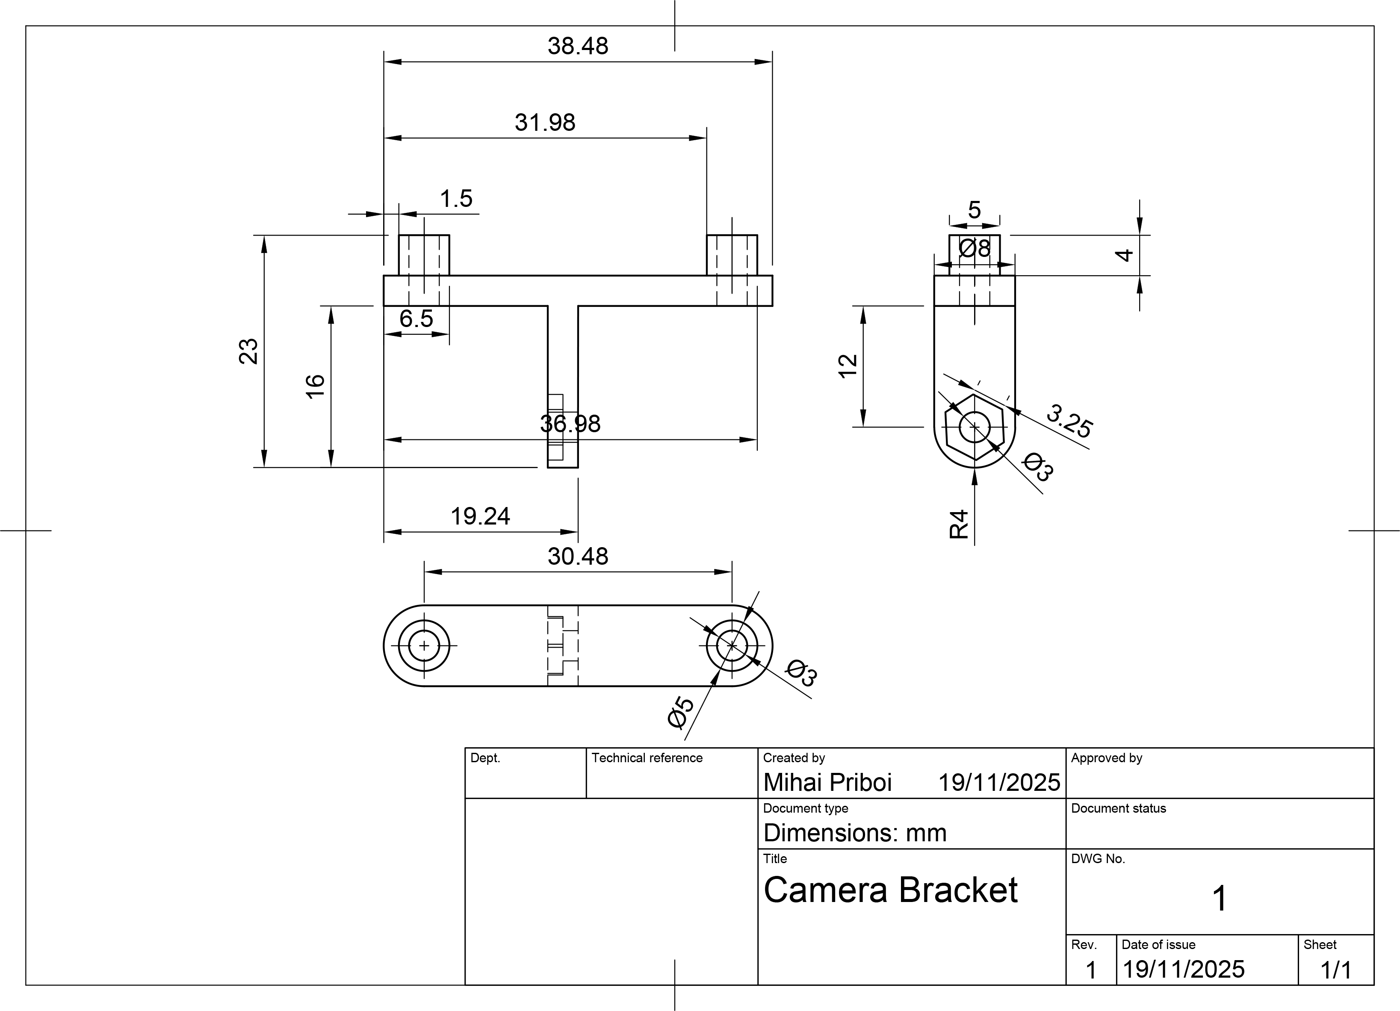
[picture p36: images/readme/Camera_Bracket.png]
Camera Bracket


<br>

**Potential Improvements**:
- Add vibration-damping materials to minimize disturbances during operation.
- Implement a more aerodynamic shape to reduce drag and improve speed (if applicable at its speed).
- Integrate a suspension system to enhance stability when turning.
- Explore the possibility of using cnc aluminium for the chassis for improved durability.
- Add a protective cover to shield the components from dust and debris.

# Power and Sense Management 

The robot's power and sense management system is composed of several components, including a Li-Po battery, an Arduino Nano ESP32, an IMU sensor, and an OpenMV Cam RT1062. These components work together to provide the robot with the necessary power and sensory input to navigate its environment effectively.

### Li-Po Battery 

<table>
  <tr>
    <td width="50%" style="text-align: left;">
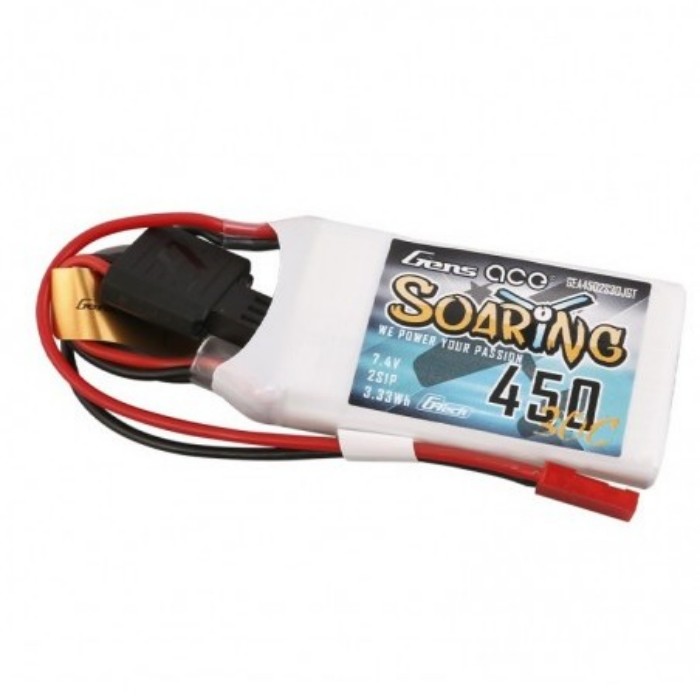
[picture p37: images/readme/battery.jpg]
Li-Po Battery
      
    </td>
    <td width="50%" style="text-align: left; vertical-align: top;">
      <h3>Specifications:</h3>
      <li>Capacity: 450mAh</li>
      <li>Voltage: 7.4V/2S</li>
      <li>Discharge rate: 30C</li>
      <li>Weight: 33 g</li>
      <li>Size: 56.5*31*9mm</li>
    </td>
  </tr>
</table>

Where to buy the battery: https://hpi-racing.ro/li-po-2s-74v/acumulator-lipo-gens-ace-g-tech-soaring-450mah-74v-30c-2s1p-cu-jst-syp.html

The battery is mounted using a custom 3D-printed holder, which is secured to the chassis.

<br>

**Potential Improvements**:
- Consider using a higher-capacity battery to extend runtime without increasing weight significantly.
- Add a battery management system (BMS) for better charging and discharging safety.
- Implement a battery level indicator to monitor power consumption and remaining charge.

### Arduino Nano ESP32 

<table>
  <tr>
    <td width="50%" style="text-align: left;">
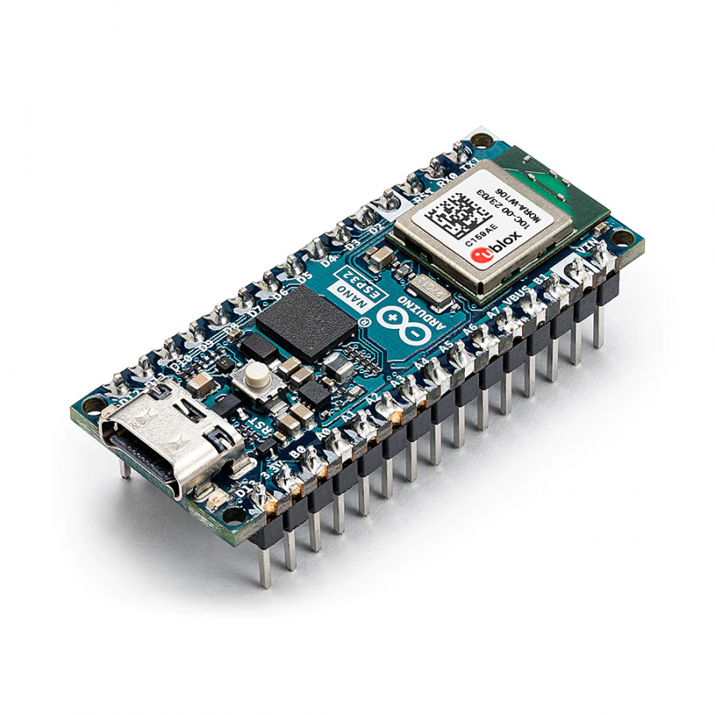
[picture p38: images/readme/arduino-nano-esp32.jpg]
Arduino Nano ESP32
      
    </td>
    <td width="50%" style="text-align: left; vertical-align: top;">
      <h3>Specifications:</h3>
      <li>Microcontroller: ESP32</li>
      <li>Flash memory: 4MB</li>
      <li>SRAM: 520KB</li>
      <li>Frequency: 240MHz</li>
      <li>Pins: 22</li>
      <li>Input voltage: 5V</li>
    </td>
  </tr>
</table>

At previous competitions, we used many microcontrollers to manage the robot's various components. This year, we opted for the Arduino Nano ESP32, which combines the functionalities of an Arduino Nano and an ESP32. This microcontroller is capable of handling all of the robot's sensors and actuators, providing a more streamlined and efficient solution.

Where to buy the Arduino Nano ESP32: https://store.arduino.cc/products/nano-esp32

<br>

**Potential Improvements**:
- Test alternative microcontrollers with additional processing power or I/O pins for future scalability.

### IMU 

<table>
  <tr>
    <td width="50%" style="text-align: left;">
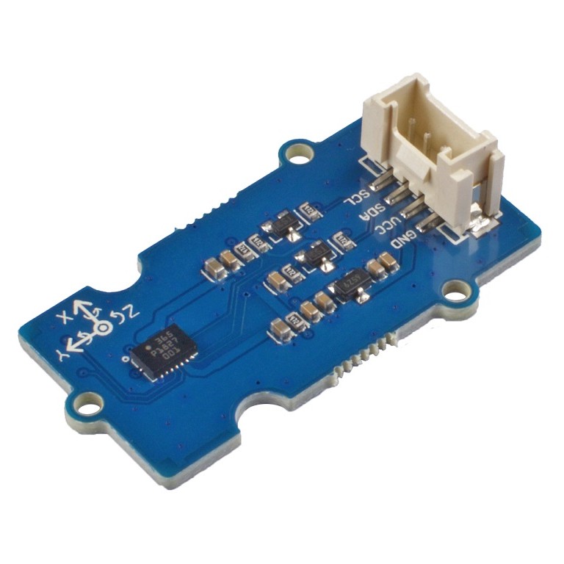
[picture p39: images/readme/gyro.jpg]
IMU Sensor - BMI088
      
    </td>
    <td width="50%" style="text-align: left; vertical-align: top;">
      <h3>Specifications:</h3>
      <li>Gyroscope range: ±2000°/s</li>
      <li>Accelerometer range: ±24g</li>
      <li>Interface: I2C</li>
      <li>Supply voltage: 1.71V to 3.6V</li>
      <li>Current consumption: 0.9mA</li>
    </td>
  </tr>
</table>

One importat aspect that helps the robot navigate is the inertial measurement unit (IMU). This sensor is based on BOSCH BMI088, which is a high-performance IMU with high vibration suppression. While the IMU measure the angular velocity and the acceleration of the robot, we only use the angular velocity to calculate the angle of the robot. The IMU is wired to the SDA and SCL pins and a additional interrupt pin on the arduino.

Where to buy the gyro sensor: https://www.seeedstudio.com/Grove-6-Axis-Accelerometer-Gyroscope-BMI088.html

<br>

**Potential Improvements**:
- Explore alternative IMU sensors with higher accuracy and better vibration resistance.
- Implement sensor fusion with additional sensors (e.g., magnetometer) for enhanced navigation.
- Test calibration procedures to minimize drift over longer runs.

### OpenMV Cam RT1062 

<table>
  <tr>
    <td width="50%" style="text-align: left;">
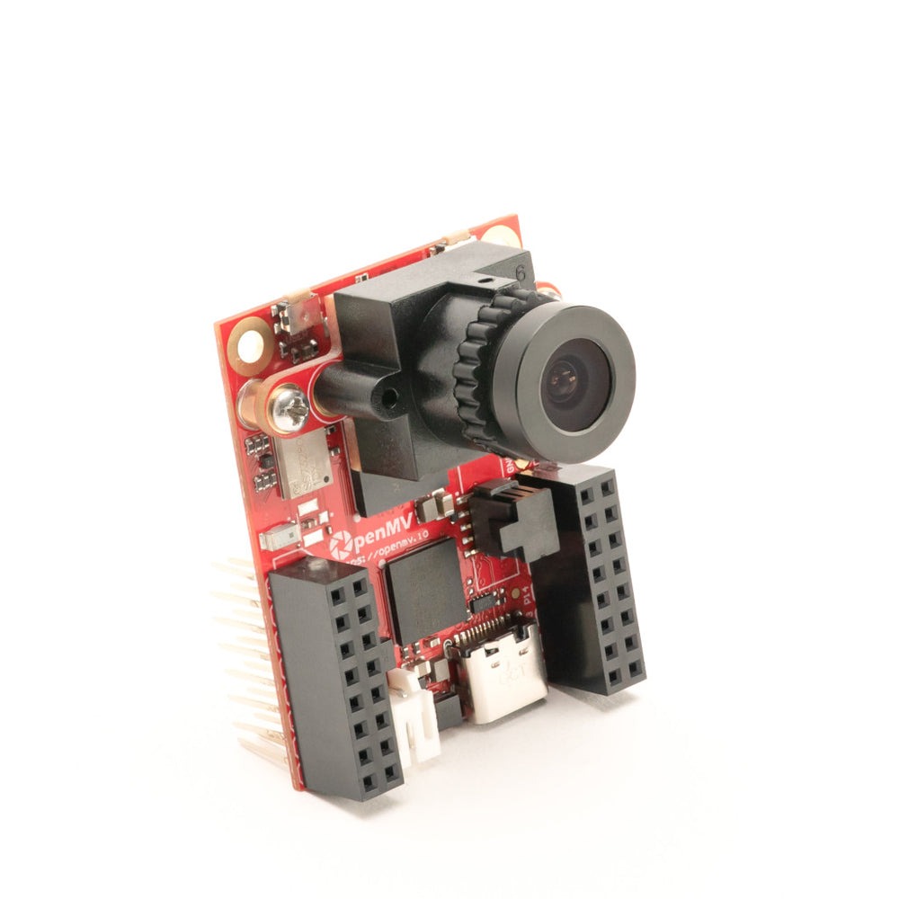
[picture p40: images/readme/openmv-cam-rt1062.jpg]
OpenMV Cam RT1062
      
    </td>
    <td width="50%" style="text-align: left; vertical-align: top;">
      <h3>Specifications:</h3>
      <li>Processor: ARM® 32-bit Cortex®-M7 CPU w/ Double Precision FPU</li>
      <li>RAM: 32MB</li>
      <li>Flash memory: 16MB</li>
      <li>Frequency: 600MHz</li>
      <li>Resolution: 2952x1944 (5MP) and under</li>
      <li>Frame rate: 60fps</li>
    </td>
  </tr>
</table>

The OpenMV Cam RT1062 is an improvement from last year's OpenMV Cam H7 R2, in most aspects (rezolution, processing speed, camera settings possibility). The OpenMV is a high-performance camera capable of color tracking. The best feature of this camera compared to other options (like the Pixy cam) is that is has a built-in microcontroller that can process the images and send the results to the Arduino. This way, the Arduino can focus on the robot's movement and the camera can focus on the image processing.

Additionally, we implemented a real-time feedback system using wifi that displays the detected colors and calibrated values on the camera's interface. This allows us to visually verify the accuracy of the color detection and make adjustments if necessary, while the robot is running.

Together with the Arduino Nano ESP32, the camera delivers readings at approximately 60 frames per second.

In order to have the lens separated from the camera body, we used the Camera Module Extension Cable

Where to buy the OpenMV Cam RT1062: https://openmv.io/products/openmv-cam-rt
Where to buy the Camera Module Extension Cable: https://openmv.io/products/camera-module-extension-cable

<br>

**Potential Improvements**:
- Test alternative lighting solutions to improve visibility in various conditions.
- Implement advanced image processing algorithms to enhance detection accuracy.
- Use color correction algorithms: Apply color correction algorithms to compensate for any variations in lighting conditions. These algorithms can adjust the color values of the captured image to match a reference color space, making the colors more consistent and easier to calibrate.

### Voltage regulator 

<table>
  <tr>
    <td width="50%" style="text-align: left;">
      Voltage regulator
    </td>
    <td width="50%" style="text-align: left; vertical-align: top;">
      <h3>Specifications:</h3>
      <li>Input voltage: 35V max</li>
      <li>Output voltage: 5V</li>
      <li>Output current: 1.5A</li>
      <li>Thermal shutdown circuit</li>
      <li>Short-circuit protection</li>
    </td>
  </tr>
</table>

To provide the Arduino Nano ESP32 with the required 5V, we needed to decrease the output from the 7.4V battery, which can reach up to 8.4V when fully charged. We employed a linear voltage regulator, the L7805CV, capable of converting input voltages below 35V down to a steady 5V.

Where to buy the 5V voltage regulator: https://ro.mouser.com/ProductDetail/STMicroelectronics/L7805CV?qs=9NrABl3fj%2FqplZAHiYUxWg%3D%3D

<br>

**Potential Improvements**:
- Replace the linear voltage regulator with a switching regulator for better efficiency.
- Add heat sinks to the regulator for improved thermal management.

### PCB design 

The robot's PCB was designed using KiCad software. The PCB integrates the voltage regulator, headers for connecting the Arduino Nano ESP32, motor driver, and camera body directly on it. We used headers in order to make the connections modular and easy to disassemble if needed for maintenance or upgrades. The PCB also includes connectors for the battery, motor, servo, and IMU sensor.

| PCB Rendered |
| :--: |
| PCB connections | 
| Empty PCB |
| PCB empty | 
| PCB |
| PCB |

Where we bought the PCB: https://jlcpcb.com/

<br>

**Potential Improvements**:
- Integrate debugging points on the PCB to simplify troubleshooting.

### Circuit diagram 
Circuit diagram

<br>

# Code for each component 

## Drive Motor 

The motor driver can be directly managed with a single PWM pin that adjusts the motor's speed and two digital pins designated for determining the motor's rotation direction. Consequently, the use of any external library for motor manipulation was unnecessary.

We devised two functions within our control system: one to modify the motor's velocity and another to halt it effectively, incorporating a braking feature. To achieve this, we convert the desired speed from our established scale of -100 to +100 to the PWM equivalent of 0 to 1023. The motor's direction is then adjusted according to the sign of the input value.

Given the fact that the Arduino has an ESP chip, the PWM signals have to be sent using the ```ledc``` utility.

```ino
void motor_driver_setup() {
  ledcSetup(DRIVER_PWM_CHANNEL, PWM_FREQ, PWM_RES);
  ledcAttachPin(PWMA, DRIVER_PWM_CHANNEL);

  pinMode(AIN1, OUTPUT);
  pinMode(AIN2, OUTPUT);
}

void move_motor(double speed) {  // move the motor with a given speed in the [-100, 100] interval
  int dir = 1;
  if (speed < 0) {
    dir = -1;
    speed *= -1;
  }
  else if (speed == 0) {
    dir = 0;
  }
  speed = map_double(speed, 0, 100, 0, 1023);
  if (dir == 1) { // move the motor forward
    digitalWrite(AIN1, HIGH);
    digitalWrite(AIN2, LOW);
  }
  else if (dir == -1) { // move it backwards
    digitalWrite(AIN1, LOW);
    digitalWrite(AIN2, HIGH);
  }
  else { // implement active break (not used since we don't know how reliable it is)
    digitalWrite(AIN1, LOW);
    digitalWrite(AIN2, LOW);
  }
  ledcWrite(DRIVER_PWM_CHANNEL, (int)speed); // write the speed using PWM
}

void motor_break(long long break_time) { // stop the robot for a given time
  move_motor(-3);
  custom_delay(break_time);
}
```

However, for the encoder, we required a specialized library to handle the more complex signal processing. The library we use for interfacing with the encoder is called ```Encoder.h```.

The encoder operates with a straightforward function that we found easy to comprehend and program. In order to determine the distance in cm, we divided the returned value by 12, since the encoder measures 12 counts per revolution. Then we multiplied this with the gear ratio, wheel diameter and Pi. After that we divided by 10 to convert to cm.

Because of the way the ESP32 chip interacts with the components, in order for this library to properly work, we should select the pin numbering option as "by GPIO number", not as the default "by Arduino pin".

```ino
double read_motor_cm() {  // getting the distance driven by the motor in cm
  return GEAR_RATIO * WHEEL_DIAM * M_PI * (double)myEnc.read() / 12 / 10;
}
```

## Servo Motor 

For controlling the servo motor, we utilize the ```Servo.h``` library, which provides the necessary functions to manage the servo's movements. Initially, we configure the servo by establishing its range, defining the maximum and minimum angles it can achieve in both directions. This ensures that we can accurately position the servo within its operational limits.

```ino
void servo_setup() {
  // attach the servo to the right pin and move it to the minimum and maximum angles
  // in the end, center the servo so that we start the program moving straight
  servo.attach(SERVO_PIN);
  for (int deg = servo.read() - 1; deg >= ANGLE_MIN; deg--)
    servo.write(deg);
  custom_delay(500);
  // Serial.println("after ANGLE_MIN");
  for (int deg = servo.read() + 1; deg <= ANGLE_MID; deg++)
    servo.write(deg);
  // Serial.println("after ANGLE_MID");
  for (int deg = servo.read() + 1; deg <= ANGLE_MAX; deg++)
    servo.write(deg);
  custom_delay(500);
  // Serial.println("after ANGLE_MAX");
  for (int deg = servo.read() - 1; deg >= ANGLE_MID; deg--)
    servo.write(deg);
  custom_delay(500);
  // Serial.println("after ANGLE_MID");
  goal_deg = ANGLE_MID;
}
```

The servo motor is controlled dinamically in the loop by setting a goal angle and taking small steps towards that goal at every iteration. This way we make sure that we can send a lot of fast angle changes to the servo and get the wanted results.

The function ```move_servo``` sets the goal angle to the given parameter. If the angle is negative the motor will rotate to the right, and if it is positive, the motor will rotate to left. This way, 0 is going to be the position in which the wheels are straight. Also, the values given the motor need to be between -1 and 1, so we use a clamp function to limit the value we are going to give the motor to rotate to and an interval mapping function to map the parameter from the [-1; 1] interval to the [ANGLE_MIN; ANGLE_MAX] interval.

The function ```update_servo``` takes a small step towards the goal angle as described above.

```ino
void move_servo(double angle) {  // move the servo to the angle checkpoint by setting the goal degrees to the angle value
  goal_deg = map_double(angle, -1, 1, ANGLE_MIN, ANGLE_MAX);
}

void update_servo() { // update the servo, making it closer to the goal angle by a small step
  int current_angle_servo = servo.read();
  if (abs(current_angle_servo - goal_deg) >= ANGLE_VARIANCE_THRESHOLD) { // if we're too far off, directly write the new angle
    servo.write(goal_deg);
  }
  else {
    // increment the angle with a small step in the right direction
    // making sure we don't exceed our angle limitations
    if (current_angle_servo < goal_deg) {
      servo.write(min(current_angle_servo + STEP, ANGLE_MAX));
    }
    else if (current_angle_servo > goal_deg) {
      servo.write(max(current_angle_servo - STEP, ANGLE_MIN));
    }
  }
}

void loop() {
  // other code
  update_servo();
}
```

## Camera 

Now that we finished implementing the functions that we need to make the robot move and steer, we have to make it see the lines that trigger the turns, the cubes and the parking walls and move accordingly. To communicate with the camera, we use the ```UART``` protocol. In order for this to work, we must link the ```RX0``` pin on the arduino (the receiver pin) to the ```P4``` pin on the camera (the transmitter pin) and the ```TX1``` pin on the arduino (the transmitter pin) to the ```P5``` pin on the camera (the receiver pin). In addition, the baud rates from the ```Serial0``` object on the arduino and the ```uart``` object on the camera must match.

**Arduino code:**

```ino
void comm_setup() {
  Serial.begin(9600);
  // while(!Serial);
  blink_led(LED_BUILTIN, 500);

  Serial0.begin(19200);
  while(!Serial0); // wait for the serial to properly initialize
  blink_led(LED_BUILTIN, 500);
  receivedMessage = "";
}

void loop() {
  // execute pending commands
  while (Serial0.available() > 0) { // if we have some characters waiting
    char receivedChar = Serial0.read(); // we get the first character
    if (receivedChar == '\n') { // if it's the end of message marker
      if (CASE != PARK) { // if we want to execute commands
        execute(receivedMessage); // execute the received command from the OpenMV camera
      }
      receivedMessage = ""; // reset the received message
    }
    else {
      receivedMessage += receivedChar; // append characters to the received message
    }
  }
}
```

**Camera code:**

```py
# setup UART connection to arduino
uart = UART(3, 19200)
# 3 - the uart config, meaning that we use pins P4 as the transmitter, P5 as the receiver
# 19200 - baud rate aka frequency, must match the one set up on the arduino

# because we have a one-sided communication going on
# we can directly write messages without any supplementary checks
uart.write(msg)
```

In order to detect colors, we have to take pictures in which to search for colors. This is the sequence that sets up the camera sensor. Due to the limitations of the sensor, we couldn't manually adjust the white balance, gain, exposure time or access its registries.

```py
import sensor

# initialize the sensor
sensor.reset()
sensor.set_pixformat(sensor.RGB565)
sensor.set_framesize(sensor.QQVGA)
#sensor.set_framerate(40)
sensor.set_vflip(True)
sensor.set_hmirror(True)

# disable auto gain, white balance, and exposure
sensor.set_auto_gain(False)  # must be turned off for color tracking
sensor.set_auto_whitebal(False)  # must be turned off for color tracking
sensor.set_auto_exposure(False, exposure_us=10000) # set constant exposure for the best visibility

# skip some frames to let the camera adjust
sensor.skip_frames(time=2000)
```

Now for the camera logic, the color tracking is pretty simple: the camera can return blobs of pixels that fit into a certain ```LAB``` threshold representing a color. We can also restrain the blob detection to a rectangle of interest and apply pixel count, bounding rectangle area and density filters as well. The reason for which we do this, is that certain colors, like green, red, blue and orange are pretty common, therefore we don't want the camera to interpret clothes or other objects outside of the map as obstacles. In addition, the orange and red colors, in some light conditions, are quite similar. This is why we apply the pixel count, bounding rectangle area and density filters, to ensure that we are seeing the correct object.

For quali we firstly scan the color of the first seen line. This will give us the direction of the run. Then, we constantly look out for lines that are over a certain area. Once we find one, we send the turn trigger to the Arduino via ```UART```.

```py
while (True):
    clock.tick()
    img = sensor.snapshot()

    # find the coloured blobs corresponding to the turn lines
    orange_blobs = img.find_blobs(orange_threshold, roi=lines_roi, pixels_threshold=line_blob_size, area_threshold=line_blob_size, merge=True)
    blue_blobs = img.find_blobs(blue_threshold, roi=lines_roi, pixels_threshold=line_blob_size, area_threshold=line_blob_size, merge=True)

    orange_blob_w = None
    orange_blob_h = None
    max_width = 0
    max_height = 0
    for blob in orange_blobs:
        if blob.w() >= img.width() * 0.4: # if it meets the minimum width requirement
            if blob.w() > max_width: # if it's the biggest blob yet
                max_width = blob.w()
                orange_blob_w = blob # biggest blob on the width
        if blob.h() >= lines_roi[3] * 0.4: # if it meets the minimum height requirement
            if blob.h() > max_height: # if it's the biggest blob yet
                max_height = blob.h()
                orange_blob_h = blob # biggest blob on the height
    # if we have a blob meeting either the minimum width or height requirement we remember it
    orange_blob = orange_blob_w
    if not orange_blob:
        orange_blob = orange_blob_h

    blue_blob_w = None
    blue_blob_h = None
    max_width = 0
    max_height = 0
    for blob in blue_blobs:
        if blob.w() >= img.width() * 0.4: # if it meets the minimum width requirement
            if blob.w() > max_width: # if it's the biggest blob yet
                max_width = blob.w()
                blue_blob_w = blob # biggest blob on the width
        if blob.h() >= lines_roi[3] * 0.4: # if it meets the minimum height requirement
            if blob.h() > max_height: # if it's the biggest blob yet
                max_height = blob.h()
                blue_blob_h = blob # biggest blob on the height
    # if we have a blob meeting either the minimum width or height requirement we remember it
    blue_blob = blue_blob_w
    if not blue_blob:
        blue_blob = blue_blob_h

    if direction == 0: # if we didn't set a turn direction yet
        if orange_blob: # if the first line we saw was an orange one
            direction = 2
        elif blue_blob: # if the first line we saw was a blue one
            direction = 1

    has_line = False
    if orange_blob or blue_blob: # if we saw either coloured lines, we can make a turn
        has_line = True

    if has_line:
        # if we must turn, send the turn trigger
        uart.write(str(direction) + '\n')
```

## IMU 

To utilize the gyro sensor, we needed to include the ```BMI088.h``` library. During initialization, we allocate a 10-second window to measure the sensor's drift, allowing us to refine the robot's angular readings for greater precision. Additionally, we configure the sensor's output data rate to 400Hz and set the bandwidth to 47Hz. The bandwidth determines the frequency of data sampling by the sensor; a higher bandwidth yields more precise data at the cost of increased power consumption. We also designate pin A6 as an input and attach an interrupt to it, enabling us to capture data from the sensor as soon as it becomes available.

```ino
void gyro_setup(bool debug) {
  int status = accel.begin();
  status = accel.setOdr(Bmi088Accel::ODR_200HZ_BW_80HZ);
  status = accel.pinModeInt1(Bmi088Accel::PUSH_PULL,Bmi088Accel::ACTIVE_HIGH);
  status = accel.mapDrdyInt1(true);

  status = gyro.begin();

  status = gyro.setOdr(Bmi088Gyro::ODR_400HZ_BW_47HZ);
  status = gyro.pinModeInt3(Bmi088Gyro::PUSH_PULL,Bmi088Gyro::ACTIVE_HIGH);
  status = gyro.mapDrdyInt3(true);

  pinMode(INT_PIN,INPUT);
  attachInterrupt(INT_PIN,gyro_drdy,RISING);

  if(status < 0) {
    if(debug){
      Serial.print("BMI Initialization Error!  error: ");
      Serial.println(status);
    }
  }
  else  {
    // Gyro drift calculation
    if(debug) Serial.println("Starting gyro drift calculation...");

    gx = 0;
    // gy = 0;
    // gz = 0;

    gyro_last_read_time = millis();

    double start_time = millis();
    while(millis() - start_time < DRIFT_TEST_TIME * 1000) {
      gyro.readSensor();
      double read_time = millis();
      gx += (gyro.getGyroX_rads() * (read_time - gyro_last_read_time) * 0.001);
      // gy += (gyro.getGyroY_rads() * (read_time - gyro_last_read_time) * 0.001);
      // gz += (gyro.getGyroZ_rads() * (read_time - gyro_last_read_time) * 0.001);

      gyro_last_read_time = read_time;
    }

    drifts_x = gx / DRIFT_TEST_TIME;
    // drifts_y = gy / DRIFT_TEST_TIME;
    // drifts_z = gz / DRIFT_TEST_TIME;

    if(debug) Serial.print("Drift test done!\nx: ");
    if(debug) Serial.println(drifts_x, 6);
    // if(debug) Serial.print("   y: ");
    // if(debug) Serial.print(drifts_y, 6);
    // if(debug) Serial.print("   z: ");
    // if(debug) Serial.println(drifts_z, 6);
  }
  // Gyro value reset
  gx = 0;
  // gy = 0;
  // gz = 0;

  gyro_last_read_time = millis();
}
```

Within the ```read_gyro``` function, we're retrieving data from the gyro sensor and adjusting it to account for any detected drift, enhancing the accuracy of the readings. Since the gyro provides data in radians, a conversion to degrees is necessary for our application. We're focusing solely on the rotation around the x-axis, hence we only compute the ```gx``` value, which represents the robot's angular rotation in degrees on that specific axis.

```ino
void read_gyro(bool debug) {
  if(gyro_flag) {
    gyro_flag = false;
    gyro.readSensor();   
    double read_time = millis();

    gx += ((gyro.getGyroX_rads() - drifts_x) * (read_time - gyro_last_read_time) * 0.001) * 180.0 / PI;
    // gy += ((gyro.getGyroY_rads() - drifts_y) * (read_time - gyro_last_read_time) * 0.001) * 180.0 / PI;
    // gz += ((gyro.getGyroZ_rads() - drifts_z) * (read_time - gyro_last_read_time) * 0.001) * 180.0 / PI;

    gyro_last_read_time = read_time;

    if(debug) {
      Serial.print("Gyro: gx: ");
      Serial.println(gx);
      // Serial.print(" gy: ");
      // Serial.print(gy);
      // Serial.print(" gz: ");
      // Serial.println(gz);
    }
  }
}
```

<br>

# Obstacle Management 

## Qualification Round 

For the qualifying round, we set up a basic switch-case system to guide our robot. This system tells the robot what to do next, depending on where it is. The robot knows where it is by counting how many times it has turned.

We use two main switch cases: ```PID``` and ```STOP_QUALI```.

In the ```PID``` case, the robot moves straight and turns. It uses a special tool (PID controller) with a gyro sensor to stay on a straight line. If it sees a corner line, it gets a trigger from the camera to make a turn by adding 90 degrees to the goal angle.

```ino
case PID: {
  check_and_execute_turnaround(gx);
  double err = current_angle_gyro - gx;
  if (millis() - last_rotate > FIRST_STOP_DELAY && turns >= 12) { // if we did 3 runs of the round
    if (FINAL) {
      CASE = STOP_BEFORE_FIND_PARKING; // we need to stop and search for the parking
    }
    else {
      CASE = STOP_QUALI; // stop, challenge over
    }
  }
  else {
    // classic pid on the gyro so that we can move straight
    pid_error_gyro = (err) * kp_gyro + (pid_error_gyro - pid_last_error_gyro) * kd_gyro;
    pid_last_error_gyro = pid_error_gyro;
    move_servo(pid_error_gyro);
  }
  move_motor(MOTOR_SPEED);
  break;
}

case STOP_QUALI: {
  // we finished the challenge, stop the robot
  move_until_angle(MOTOR_SPEED, current_angle_gyro);
  move_cm_gyro(10, MOTOR_SPEED, current_angle_gyro);
  is_running = false;
  Serial.println("Stop case");
  motor_break(1000000000);
}
```

### Line Detection
Line Detection

## Final Round 

For the final round, we based our controller algorithm on the quali code, adding a PID controller on the camera to follow the closest cube until it is in its proximity. In order to get the closest cube to the robot we just search for the biggest red or green coloured blob in the image.
After we're in the cube's proximity, we send a trigger from the camera to the arduino with the cube color so that we can start avoiding it.

```py
img = sensor.snapshot()

# find the coloured blobs corresponding to the cubes
red_blobs = img.find_blobs(red_threshold, roi=cubes_roi, pixels_threshold=min_cube_size, area_threshold=min_cube_size, merge=True)
green_blobs = img.find_blobs(green_threshold, roi=cubes_roi, pixels_threshold=min_cube_size, area_threshold=min_cube_size, merge=True)

msg = "0\n"
max_area = 0
color = 'none'
saved_cube = None
for blob in red_blobs: # for every red blob
    # if they're passing the height and density filters
    # we're keeping the biggest one and its color
    if is_cube(blob, orange_blob, parking_blobs) and blob.area() > max_area:
        max_area = blob.area()
        saved_cube = blob
        color = 'red'
for blob in green_blobs: # for every green blob
    # if they're passing the height and density filters
    # we're keeping the biggest one and its color
    if is_cube(blob, blue_blob, parking_blobs) and blob.area() > max_area:
        max_area = blob.area()
        saved_cube = blob
        color = 'green'

if saved_cube != None: # if we saw a cube
    # if the cube area is over a certain threshold
    # it means we must avoid the cube as we are too close to it
    if (color == 'red' and saved_cube.pixels() >= max_cube_size_red) or (color == 'green' and saved_cube.pixels() >= max_cube_size_green):
        # send the right trigger
        if color == 'red':
            uart.write('R\n')
        else:
            uart.write('G\n')
        if has_line:
            # if we must also turn, send the trigger
            uart.write(str(direction) + '\n') # send the turn trigger
    else: # if the cube isn't too big we must follow it
        # calculate the angle using PID
        err = saved_cube.cx() - img.width() / 2
        steering = err * kp + (err - err_old) * kd
        steering = -clamp(steering, -1, 1)
        err_old = err
        # craft the command
        if color == 'red':
            msg = 'r' + str(steering) + '\n'
        else:
            msg = 'g' + str(steering) + '\n'
        uart.write(msg) # send the message
        if has_line:
            # if we must also turn, send the turn trigger
            uart.write(str(direction) + '\n')
elif has_line: # if we don't see any cubes
    # if we must turn, send the turn trigger
    uart.write(str(direction) + '\n')
```

### Cube Detection
Red Cube Detection
Green Cube Detection

---

The arduino part is quite simple, consisting of the quali switch but with two extra cases: ```FOLLOW_CUBE``` and ```AFTER_CUBE```. In the ```FOLLOW_CUBE``` case we just write to the servo the steering angle calculated by the PID algorithm ran on the camera. After we get the proximity trigger from the camera, we have a custom function called ```pass_cube``` which steers us away from the cube and puts us in the ```AFTER_CUBE``` state. This case consists of two substates: in the first one the robot steers in the opposite direction to center itself again and the second one in which the robot uses a PID with the gyro to move an additional distance so that we're perfectly positioned to see the next cube. After that, we go back to the default ```PID``` case that is used in the quali code.

```ino
// hardcoded sequence that avoids a cube
void pass_cube(int cube_last) {
  int angle_addition = 0;
  if (cube_last == 1) // due to a slight asymmetry in the steering, when avoiding red cubes we need to steer less
    angle_addition = -9;
  read_gyro(false);
  int start_angle = gx;
  move_until_angle(MOTOR_SPEED, start_angle - cube_last * (AVOIDANCE_ANGLE + angle_addition)); // steer away from the cube
  // gain some distance
  if (abs(current_angle_gyro - start_angle) >= 10) // if we passed by it while crooked in regards to the goal line we need to overcompensate in order to see the next cube
    move_cm_gyro(16, MOTOR_SPEED, start_angle - cube_last * (AVOIDANCE_ANGLE + angle_addition));
  else
    move_cm_gyro(7, MOTOR_SPEED, start_angle - cube_last * (AVOIDANCE_ANGLE + angle_addition));
  CASE = AFTER_CUBE;
}
```

```ino
case FOLLOW_CUBE: {
  check_and_execute_turnaround(gx);
  if (millis() - last_rotate > FIRST_STOP_DELAY && turns >= 12) { // if we did 3 runs of the obstacle round, we need to stop and search for the parking
    CASE = STOP_BEFORE_FIND_PARKING;
  }
  else {
    if (millis() - last_follow_cube > FOLLOW_CUBE_DEAD_TIME) // if we lost the cube, we just go back to the default PID case
      CASE = PID;
    // write to the servo the pid computed on the camera in order to follow the cube
    move_servo(follow_cube_angle);
    move_motor(MOTOR_SPEED);
  }
  break;
}

case AFTER_CUBE: {
  check_and_execute_turnaround(gx);
  if (millis() - last_rotate > FIRST_STOP_DELAY && turns >= 12) { // if we did 3 runs of the obstacle round, we need to stop and search for the parking
    CASE = STOP_BEFORE_FIND_PARKING;
  }
  else {
    double err = current_angle_gyro - gx + cube_last * CORRECTION_ANGLE;
    if (abs(err) < 5) {
      // after we avoid the cube, move forward a bit more so that we're positioned
      // to see the next cube
      if (cube_last == turn_direction) // compensate less on the inside
        move_cm_gyro(5, MOTOR_SPEED, current_angle_gyro + cube_last * CORRECTION_ANGLE);
      else
        move_cm_gyro(10, MOTOR_SPEED, current_angle_gyro + cube_last * CORRECTION_ANGLE);
      CASE = PID;
    }
    else {
      // classic pid on the gyro so that we can move in the opposite direction
      // so that we can see the next cube
      pid_error_gyro = (err) * kp_gyro + (pid_error_gyro - pid_last_error_gyro) * kd_gyro;
      pid_last_error_gyro = pid_error_gyro;
      move_servo(pid_error_gyro);
    }
  }
  move_motor(MOTOR_SPEED);
  break;
}
```

The next challenge in this round consists in the final turnaround. If the last seen cube is red, we need to do a roundabout and complete the last lap in the opposite direction. The way we deal with this is a function that checks if we should turn around and executes it if necessary. This function is called in the ```PID```, ```FOLLOW_CUBE``` and ```AFTER_CUBE``` cases.

```ino
void check_and_execute_turnaround(double gx) {
  // if we didn't do the turnaround yet
  // and we did 2 runs of the map
  // and the last seen cube is red
  // and some time passed since the 8th turn
  // (so that we can see the first cube in the starting sequence in case this sequence had 2 cubes and we spawned between them)
  if (!FINAL)
    return;
  if (!TURNED && turns == 8 && cube_last == 1 && millis() - last_rotate > TURNAROUND_DELAY) { // may have to take out the time condition for any case except AFTER_CUBE
    move_until_angle(MOTOR_SPEED, current_angle_gyro + turn_direction * TURNAROUND_ANGLE);
    if (-cube_last == turn_direction) { // if i avoided the cube on the inside, i don't have too much room
      move_cm_gyro(5, MOTOR_SPEED, current_angle_gyro + turn_direction * TURNAROUND_ANGLE); // position ourselves so that we have room to turn around
    }
    else {
      move_cm_gyro(17, MOTOR_SPEED, current_angle_gyro + turn_direction * TURNAROUND_ANGLE); // position ourselves so that we have room to turn around
    }
    turn_direction *= -1;
    current_angle_gyro += turn_direction * 180;
    move_until_angle(MOTOR_SPEED, current_angle_gyro + turn_direction * TURNAROUND_ANGLE);
    TURNED = true;
    CASE = PID;
  }
}
```

The final challenge in this round consists in parking the robot. The way we implement this is based on the quali. Basically we want to move as close to the outer walls as possible so that we're perfectly positioned for the parking and avoid all of the cubes. How we achieve this is by going perpendicular to the outside walls after we finish the obstacle round (see the ```POSITION_BEFORE_FIND_PARKING``` case). The goal is to position ourselves as close as possible to them. After we receive a trigger from the camera saying that we're in its proximity, we straighten ourselves out and start the basic quali code.

While moving around the map like this (in the ```FIND_PARKING``` case), we are constantly scanning for magenta blobs that represent the parking walls. When we detect them, we send a trigger from the camera to the arduino and then we have a hardcoded sequence that puts us between the walls, perfectly parallel to them, implemented in the ```POSITION_FOR_PARK``` case. After that, we move straight in order to get closer to the outer wall (see the ```PARK``` case). When we receive the trigger from the camera, move a couple of cm straight and stop the robot.

Camera code:

```py
# find the coloured blobs corresponding to the parking walls
parking_blobs = img.find_blobs(parking_threshold, roi=parking_roi, pixels_threshold=parking_blob_size_min, area_threshold=parking_blob_size_min, merge=True)
parking_wall_blob = get_biggest_blob(parking_blobs)

# find the coloured blobs corresponding to the outside walls
wall_blobs = img.find_blobs(black_threshold, roi=wall_roi, pixels_threshold=wall_blob_size, area_threshold=wall_blob_size, merge=True)
outer_wall = get_biggest_blob(wall_blobs)

if is_parking_wall(parking_wall_blob):
    # if we saw the parking walls, send the parking trigger
    uart.write('P\n')
if wall_blobs:
    # if the wall is big enough, send a slightly different message that helps us when parking
    # if not, send the classic one
    if outer_wall.pixels() >= wall_roi_area and outer_wall.area() >= wall_roi_area:
        uart.write('WP\n')
    else:
        uart.write('W\n')
```

### Parking Wall Detection
Parking Wall Detection

---

**Arduino code:**

```ino
case STOP_BEFORE_FIND_PARKING: {
  // straighten ourselves, start searching for the parking
  motor_break(1000);
  CASE = POSITION_BEFORE_FIND_PARKING;
  break;
}

case POSITION_BEFORE_FIND_PARKING: {
  // classic pid on the gyro so that we can move perpendicular to the walls
  // we don't just call the move_until_angle function so that we can still execute commands
  double err = current_angle_gyro - gx - turn_direction * 90;
  pid_error_gyro = (err) * kp_gyro + (pid_error_gyro - pid_last_error_gyro) * kd_gyro;
  pid_last_error_gyro = pid_error_gyro;
  move_servo(pid_error_gyro);
  move_motor(MOTOR_SPEED);
  break;
}

case FIND_PARKING: {
  // classic pid on the gyro so that we can move straight
  // basically immitating a quali run until we find the parking spot
  double err = current_angle_gyro - gx;
  pid_error_gyro = (err) * kp_gyro + (pid_error_gyro - pid_last_error_gyro) * kd_gyro;
  pid_last_error_gyro = pid_error_gyro;
  move_servo(pid_error_gyro);
  move_motor(MOTOR_SPEED);
  break;
}

case POSITION_FOR_PARK: {
  // hardcoded sequence of moves that positions us in the parking spot
  // after that, we just get closer to the outside wall so that we're fully in
  move_cm_gyro(10, PARKING_SPEED, current_angle_gyro);
  move_until_angle(PARKING_SPEED, current_angle_gyro + turn_direction * 90);
  move_until_angle(PARKING_SPEED, current_angle_gyro - turn_direction * 90);
  CASE = PARK;
  break;
}

case PARK: {
  // classic pid on the gyro so that we can move straight into the parking space
  // we don't just call the move_until_angle function so that we can still execute commands
  double err = current_angle_gyro - gx - turn_direction * 90;
  pid_error_gyro = (err) * kp_gyro + (pid_error_gyro - pid_last_error_gyro) * kd_gyro;
  pid_last_error_gyro = pid_error_gyro;
  move_servo(pid_error_gyro);
  move_motor(PARKING_SPEED);
  break;
}

case STOP_FINAL: {
  // we finished the challenge, stop the robot
  is_running = false;
  Serial.println("Stop case");
  motor_break(1000000000);
}
```

## Additional code 

**Arduino code:**

In order to clean up the code, we designed some additional functions. Whenever we want to call locomotion functions or delay functions, functions that would break the continuity of the loop function, we must do two things to make sure everything keeps working: flush the characters sent by the camera (using the ```flush_messages``` function) and read the gyro data. That's why we implemented a custom delay function and our locomotion functions are a bit atypical.

```ino
void flush_messages() { // flushing messages like this so that we don't get sections of messages
  // improves the stability of the communication
  while (Serial0.available() > 0) { // if we have some characters waiting
    char receivedChar = Serial0.read(); // we get the first character
    if (receivedChar == '\n') { // if it's the end of message marker
      receivedMessage = ""; // reset the received message
    }
    else {
      receivedMessage += receivedChar; // append characters to the received message
    }
  }
}

void custom_delay(long long delay_time) { // delay function that flushes all of the data
  long long start_time = millis();
  while (millis() - start_time < delay_time) {
    read_gyro(false);
    flush_messages();
  }
}
```

Functions used for locomotion:
```ino
// makes the robot move until it reaches a certain gyro angle
void move_until_angle(double speed, double gyro_offset) {
  int sign = 1;
  if (speed < 0) // if we're moving backwards, we need to steer in the opposite direction
    sign = -1;
  read_gyro(false);
  double err = gyro_offset - gx;
  while (abs(err) >= 10) { // while the error is too big
    // pid on the gyro so that we're moving towards the goal angle
    read_gyro(false);
    err = gyro_offset - gx;
    pid_error_gyro = (err) * kp_gyro + (pid_error_gyro - pid_last_error_gyro) * kd_gyro;
    pid_last_error_gyro = pid_error_gyro;
    move_servo(pid_error_gyro * sign);
    update_servo();
    move_motor(speed);
    flush_messages();
  }
}

// makes the robot move a certain distance at a certain gyro angle
void move_cm_gyro(double dis, double speed, double gyro_offset) {
  double start_cm = read_motor_cm();
  int sign = 1;
  if (speed < 0) // if we're moving backwards, we need to steer in the opposite direction
    sign = -1;
  while (abs(read_motor_cm() - start_cm) < dis) { // while we haven't moved the requested distance
    // pid on the gyro so that we're moving at the correct angle
    read_gyro(false);
    double err = gyro_offset - gx;
    pid_error_gyro = (err) * kp_gyro + (pid_error_gyro - pid_last_error_gyro) * kd_gyro;
    pid_last_error_gyro = pid_error_gyro;
    move_servo(pid_error_gyro * sign);
    update_servo();
    move_motor(speed);
    flush_messages();
  }
}
```

Lastly, we receive multiple types of commands from the camera, from different triggers, to cube following and avoiding commands. All of these take various forms, therefore we need a function that parses every command and executes it. This is where the ```execute``` and ```valid_command``` functions come in handy. The ```execute``` function executes the command only if the ```valid_command``` function says it's valid.

```ino
bool valid_command(String cmd) { // function that checks the validity of a command received from the camera
  if (cmd == "")
    return false;
  if ('0' <= cmd[0] && cmd[0] <= '9') {
    if (cmd[0] > '2' || cmd[0] == '0')
      return false;
    if (cmd.length() != 1)
      return false;
  }
  if (cmd[0] == '+' || cmd[0] == '-' || cmd[0] == '.')
    return false;
  return true;
}

// function that parses a command and executes it
void execute(String cmd) {
  if (!valid_command(cmd))
    return;

  // the following sequence gets the number from the command (if available)
  int pos = 0, sign = 1;
  if (cmd[pos] == 'r' || cmd[pos] == 'g')
    pos++;
  // manually going over the signs since the .toDouble function wouldn't parse them on its own
  if (cmd[pos] == '+')
    sign = 1, pos++;
  else if (cmd[pos] == '-')
    sign = -1, pos++;
  double val = cmd.substring(pos).toDouble();

  if (FINAL) { // if we're in the final round
    if (CASE == FIND_PARKING && cmd[0] == 'P') { // if we're searching for the parking spot and we find it
      CASE = POSITION_FOR_PARK; // park the robot
      return;
    }

    if (cmd[0] == 'P') // if we see the parking slot, but we didn't finish the obstacle round we ignore it
      return;

    if (CASE == POSITION_BEFORE_FIND_PARKING && cmd[0] == 'W') { // if we're positioning ourselves close to the wall and we're in its proximity
      move_until_angle(MOTOR_SPEED, current_angle_gyro); // straighten ourselves
      CASE = FIND_PARKING; // start searching for the parking lot
      return;
    }

    if (CASE == PARK && (cmd[0] == 'W' && cmd[1] == 'P')) { // if we're positioning ourselves close to the wall and we're in its proximity
      move_cm_gyro(2, PARKING_SPEED, current_angle_gyro - turn_direction * 90); // position ourselves closer
      CASE = STOP_FINAL; // we finished the parking, stop
      return;
    }

    if (cmd[0] == 'W') // if we see the outer wall, but we don't need it we ignore it
      return;

    if (CASE != FIND_PARKING && CASE != POSITION_BEFORE_FIND_PARKING) {
      if (cmd[0] == 'R' || cmd[0] == 'G') { // if we're in the proximity of a cube
        if (cmd[0] == 'R') { // we determine the direction in which we avoid the cube
          cube_last = 1;
        }
        else {
          cube_last = -1;
        }
        pass_cube(cube_last);
        return;
      }
      if (cmd[0] == 'r' || cmd[0] == 'g') { // if we see a cube but we're not close enough to avoid it
        follow_cube_angle = val * sign;
        CASE = FOLLOW_CUBE;
        last_follow_cube = millis();
        return;
      }
    }
  }
  
  int msg = (int)val;
  if (msg) { // a turn was detected
    if (turn_direction == 0) { // if we don't know the direction yet
      if (msg == 1) { // blue line
        turn_direction = 1;
      }
      else { // orange line
        turn_direction = -1;
      }
    }
    if (millis() - last_rotate > delay_walls) { // if we can make a turn
      if (CASE == FIND_PARKING) { // if we're searching for the parking spot
        // if we're at the first turn, we have to move more in order to position ourselves close to the outer walls
        move_cm_gyro(CORNER_DISTANCE_PARKING, MOTOR_SPEED, current_angle_gyro);
      }
      else if (0 < (current_angle_gyro - gx) * turn_direction && (current_angle_gyro - gx) * turn_direction < 10) { // if we're during the obstacle round or in the quali and we're straight
        // position ourselves in order to not hit the walls
        if (FINAL)
          move_cm_gyro(CORNER_DISTANCE_FINAL, MOTOR_SPEED, current_angle_gyro);
        else
          move_cm_gyro(CORNER_DISTANCE_QUALI, MOTOR_SPEED, current_angle_gyro);
      }
      else if (CASE == AFTER_CUBE) { // if we're crooked after avoiding a cube we position ourselves for the turn
        if (-cube_last == turn_direction) { // if we passed by it in the turn's direction then we just need to straighted ourselves for more manuver room
          move_until_angle(MOTOR_SPEED, current_angle_gyro);
        }
        else {
          move_until_angle(MOTOR_SPEED, current_angle_gyro + turn_direction * 30);
          move_cm_gyro(7, MOTOR_SPEED, current_angle_gyro + turn_direction * 30);
        }
        CASE = PID;
      }
      current_angle_gyro += turn_direction * 90; // update the goal angle for the next sequence
      turns++; // increase the number of turns made
      delay_walls = 2500; // larger delay for every turn except the first one
      // as we may have the starting position close to the first turn
      last_rotate = millis(); // update the last time we turned
    }
  }
}
```

**Camera code:**

In order to make the robot more stable in any light conditions, we had to make sure that the red, orange and magenta, respectively the green and the blue colors don't get confused in the color detection process. That's why in order to ensure the best accuracy we fine tuned our color thresholds so that we can never see magenta/orange on a red cube or blue on a green cube. The problem that remained is that we saw red in magenta/orange and green in blue. That's why we came up with a simple solution: if a red/green blob is inside another blob that can be mixed up with, such as a line blob or a parking wall blob, we simply ignore it, as it is a false cube detected.

```py
# detects if a blob is partially inside another blob
# by checking if the center of one blob is inside the minimum area rectangle that wraps the other blob
# giving the fact that this rectangle may be crooked, we have to use a special algorithm
# that is designed to check whether a point is inside a polygon or not based on the coordinates
def is_blob_in_blob(blob, blob2):
    if not blob2:
        return False
    polygon = blob2.min_corners()
    num_vertices = len(polygon)
    (x, y) = (blob.cx(), blob.cy())
    inside = False

    # store the first point in the polygon
    (p1x, p1y) = (polygon[0][0], polygon[0][1])

    # loop through each edge in the polygon
    for i in range(1, num_vertices + 1):
        # get the next point in the polygon
        (p2x, p2y) = (polygon[i % num_vertices][0], polygon[i % num_vertices][1])

        # check if the point is above the minimum y coordinate of the edge
        # check if the point is below the maximum y coordinate of the edge
        # check if the point is to the left of the maximum x coordinate of the edge
        if y > min(p1y, p2y) and y <= max(p1y, p2y) and x <= max(p1x, p2x):
            # calculate the x-intersection of the line connecting the point to the edge
            x_intersection = (y - p1y) * (p2x - p1x) / (p2y - p1y) + p1x

            # check if the point is on the same line as the edge or to the left of the x-intersection
            if p1x == p2x or x <= x_intersection:
                # flip the inside flag
                inside = not inside

        # store the current point as the first point for the next iteration
        (p1x, p1y) = (p2x, p2y)

    # return the value of the inside flag
    return inside

# checks whether a blob is a cube or not based on the minimum height and density filters
# as well as another check:
# since in some light conditions the red the cube may be similar to the orange line or magenta parking walls
# and in some light conditions the green the cube may be similar to the blue line
# we have to check if the possible cube blob is inside any of these ones
# if it is, then it may just be a false alarm and we should ignore it
def is_cube(blob, line_blob, parking_blobs):
    if blob.density() >= density_thr and blob.h() > min_cube_height and not is_blob_in_blob(blob, line_blob):
        for parking_wall_blob in parking_blobs:
            if is_blob_in_blob(blob, parking_wall_blob):
                return False
        return True
    return False
```

In addition, we created the following functions in order to avoid code repetition or to break down complicated conditions.

```py
# function that gets the biggest blob by size
def get_biggest_blob(blob_array):
    max_area = 0
    max_blob = None
    for blob in blob_array:
        # we're keeping the biggest parking blob
        if blob.area() > max_area:
            max_area = blob.area()
            max_blob = blob
    return max_blob

# checks if a parking wall blob meets the height and size requirements
def is_parking_wall(blob):
    if not blob:
        return False
    if blob.pixels() >= parking_blob_size_trigger and blob.area() >= parking_blob_size_trigger:
        return True
    if blob.h() >= parking_blob_height_trigger:
        return True
    return False
```

<br>

# What We Changed This Year 

The mechanical robot above is basically the L.A.C.H.E. we ended last season with, and we were happy with it, so this year almost all of our work went into the software. The strategy in the two sections above (the switch-case quali run and the cube-following final) is still the backbone of how the robot competes. What follows is everything we built on top of it: a way to actually see what the robot is thinking, a gyro that no longer drifts, a car that calibrates its own steering, and the start of a localization system that lets us drive the track from memory instead of reacting to it corner by corner.

A note before the WiFi part, because it matters: **WiFi is a pit tool, not a race tool.** During an official run the radio is off and the robot is completely on its own (the camera still talks to the Arduino over UART, exactly like before). Everything described here that uses WiFi is something we use on the bench to tune and to understand the robot faster, and then we turn it off and let the calibrated values do the work.

## Tuning and telemetry over WiFi 

Last year, tuning meant plugging in a USB cable, opening the serial monitor, changing a number, re-flashing, and unplugging again, for every single value. With a car that has to be put back on the floor to actually test anything, that loop was painfully slow.

So this year the Arduino Nano ESP32 doubles as its own WiFi access point. It starts a little network called `ROBOT_Fut`, serves a single web dashboard, and pushes live data to the browser over a WebSocket about twenty times a second. From a phone or a laptop, with the robot running on its battery on the floor, we can watch the heading, the steering angle, the encoder distance and the live camera view, and we can nudge any of the tuning parameters and see the effect immediately, no cable, no re-flash.

```ino
void setup() {
  // ... sensors and actuators set up first ...

  WiFi.mode(WIFI_AP);
  WiFi.softAP(AP_SSID, AP_PASS);              // "ROBOT_Fut" / "futeng2026"

  ws.onEvent(onWsEvent);                      // commands come back from the page
  server.addHandler(&ws);
  server.on("/", HTTP_GET, [](AsyncWebServerRequest *r) {
    r->send_P(200, "text/html", INDEX_HTML);  // the dashboard lives in flash
  });
  server.begin();
}

void loop() {
  // push a small JSON telemetry packet to every open browser, ~20 Hz
  if (millis() - lastPush >= 50) {
    lastPush = millis();
    if (ws.count() > 0) ws.textAll(telemetry());
  }
}
```

The same page also embeds the camera's own live stream. The OpenMV cam runs a tiny server that sends the raw image, and all the heavy color-tuning (picking a region, averaging the LAB values, previewing the mask) happens in the browser on the laptop, not on the camera. The camera just stores whatever thresholds we settle on into a small `thresholds.json` that the run code reads at startup. Calibrating colors went from "re-flash and pray" to dragging a box on a live image.

```py
# on the OpenMV cam: stream the frame, keep the tuned colors
def handle_save(query):           # GET /save?g=...&r=...
    thr = parse_thresholds(query)
    with open("thresholds.json", "w") as f:
        json.dump(thr, f)         # the robot reads these back at boot
    return "ok"
```

This one change is the reason everything below got built: once you can *see* the robot's numbers in real time, the bugs and the bad calibrations that used to hide for hours become obvious in minutes.

## A drift-free gyro that finds its own straight 

The gyro has always been the heart of how we drive straight, but last year it had a weakness. At boot we measured its drift once over ten seconds and then trusted that number for the whole run. It worked, but the bias of a MEMS gyro moves a little as the chip warms up, so by the third lap the heading had quietly walked off by a couple of degrees, and a couple of degrees is the difference between a clean lap and clipping a wall.

This year we rebuilt the gyro pipeline. The BMI088 now streams at 1000 Hz and raises a data-ready interrupt on every new sample, so the heading is integrated from a steady, high-rate stream the moment each reading lands, instead of whenever the main loop happened to get around to it. More importantly, the drift correction never stops: whenever the readings are quiet enough that the car is clearly standing still, we keep nudging the measured drift towards what the sensor reports. It's a continuous zero-rate update, and the effect is that the heading basically stops drifting, over a full run it stays within about a tenth of a degree.

```ino
// fires on every new gyro sample (data-ready interrupt), ~1000 Hz
void read_gyro(bool debug) {
  if (gyro_flag) {
    gyro_flag = false;
    gyro.readSensor();
    double read_time = millis();
    double rate = gyro.getGyroX_rads();   // raw turn rate, rad/s

    // continuous zero-rate update: while the car is clearly standing still,
    // keep nudging the measured drift towards the true zero
    if (fabs(rate - drifts_x) < STILL_RATE_THRESH) still_count++;
    else still_count = 0;
    if (still_count >= STILL_SAMPLES)
      drifts_x += ZRU_ALPHA * (rate - drifts_x);

    // integrate the bias-corrected rate into a heading, in degrees
    gx += (rate - drifts_x) * (read_time - gyro_last_read_time) * 0.001 * 180.0 / PI;
    gyro_last_read_time = read_time;
  }
}
```

A solid heading is only half of going straight, though. The other half is the steering: the servo center that actually makes the wheels point dead ahead is never a clean number, it shifts with backlash, with how the linkage settled, even with a fresh battery pushing the motor a touch harder. We used to find it by eye, write it down as `ANGLE_MID`, and re-trim it by hand whenever something changed.

Now the car finds it on its own, by training on its own driving. We lock the steering at a candidate center, drive a fixed distance forward at race speed, and read how far the gyro says we drifted. That drift *is* the error: if the car curved right, the center is too far right. So we treat "find the center that gives zero drift" as a simple root-finding problem and let a secant search walk the center value towards zero error, usually in four or five passes, then do one verification run to confirm. Between passes the car drives itself back to the start, keeping straight with the gyro, so it can repeat the test without us touching it.

```ino
// drive forward with the steering locked at C, return the net heading drift
float measureForward(int C) {
  servo.write(C);
  gyroZero();
  setMotor(+g_speed);
  while (distanceDriven() < g_distCm) { /* log heading vs distance */ }
  setMotor(0);
  return g_heading;          // this is our error signal: 0 = perfectly straight
}

// secant step: use the last two (center, drift) points to guess the next center
float nextCenter(float C, float drift, float Cprev, float driftPrev) {
  float denom = drift - driftPrev;
  if (fabsf(denom) < 1e-3f) return C + PROBE_STEP;     // nudge if it's flat
  return C - drift * (C - Cprev) / denom;              // aim straight at zero
}
```

Every pass, the measured drift and the next center it's going to try show up live on the dashboard, so we can watch it converge. The first time we ran it and the number it landed on beat the one we'd been setting by hand for weeks, that was the moment this season clicked.

## Our own localization and route memory 

Here is the bigger idea we've been chasing this year. A drift-free heading and a wheel encoder are, together, enough to know roughly *where the robot is on the mat*, not just which way it's pointing. So we built our own little localization: dead reckoning. Every time the encoder ticks, we know how far the wheels turned; combine that with the heading and you can integrate a position in centimeters.

```ino
// dead reckoning: turn the distance the wheels rolled + heading into (x, y)
void update_odometry() {
  double cm = read_motor_cm();
  double dd = cm - last_odo_cm;     // distance the wheels rolled since last call
  last_odo_cm = cm;

  double th = gx * DEG_TO_RAD;      // gx is our drift-free heading, in degrees
  robot_x += dd * sin(th);
  robot_y += dd * cos(th);

  // drop a breadcrumb every ~1.5 cm so we can rebuild the line we drove
  double ex = robot_x - last_log_x, ey = robot_y - last_log_y;
  if (ex * ex + ey * ey >= TRAIL_STEP_CM * TRAIL_STEP_CM && path_len < MAX_PATH) {
    path[path_len++] = { (float)robot_x, (float)robot_y, (float)gx, 0 };
    last_log_x = robot_x; last_log_y = robot_y;
  }
}
```

The dashboard draws this as a top-down map: the robot as an arrow, the route as a trail behind it, a grid in centimeters. We can drive the car around by holding a button on the page and literally watch the map of the track build itself. When we like a lap, we save the whole trajectory to a CSV right on the robot and pull it off over WiFi.

We're honest about the limits, because they shape everything: our encoder only has one working channel, so the *direction* of travel comes from the motor command rather than the wheels, and any sideways slip slowly accumulates into the position estimate. That means raw dead reckoning can't be trusted for a whole multi-lap run on its own. Our answer is to keep it anchored: the camera already finds the orange and blue corner lines and the walls every frame, and those are fixed, known features of the mat, so we use them to re-zero the position at each corner instead of letting the error pile up.

```py
# camera already detects the corner lines; now we also tag *where* it happened
if has_line:
    send_message(str(direction))   # same turn trigger as before
    send_message('M')              # ...plus "mark this corner on the map"
```

This is also where the camera stops being just an obstacle detector and starts shaping a clean racing line. Reacting to a corner only once you see the line gives you a late, abrupt turn. But if you've driven the track once and *recorded* the smooth line through every corner, you can drive the rest of the run from that memory, the corners come out rounded and repeatable because you're replaying a good lap instead of improvising a new one each time. Recording that line works well today; replaying it through the steering is the piece we're actively tuning, and it's the direction the whole project is pointed.

## Rethinking the parking 

Last year's parking (in the final round above) was clever but completely reactive: drive along the wall, wait until the camera sees the magenta markers, then run a hardcoded slot-in sequence and hope we were positioned well. When it worked it looked great; when the approach angle was a little off, the hardcoded part inherited that error and we'd end up crooked in the pocket.

With localization, parking turns into something we can actually reason about. The parking pocket is at a fixed place relative to the outer walls, so once we know our own position on the mat we know roughly where the pocket is *before* the camera even confirms it. The plan we're building for this season is to treat the pocket as a known waypoint: drive there on the recorded line, line up parallel using the gyro heading we trust, and only use the camera for the final centimeters of fine alignment against the magenta markers, instead of leaning on the camera for the entire maneuver. The hardcoded sequence stops being a leap of faith and becomes a short, well-positioned correction.

## Where this is heading 

Everything above is one connected bet: that the most reliable way around this track is to *know where you are* and *drive a line you've already proven*, rather than to react frame by frame. The pieces we're proud of, drift-free heading, self-calibrating steering, live tuning, and live localization, are all working. The pieces we're still fighting with are the ones that turn a recorded path back into smooth motion: tightening the dead-reckoning so it survives a full run between corner re-zeros, and closing the loop so the steering follows the saved line instead of just plotting it.

If we get there, the qualification run becomes "drive one careful lap, then replay it faster," and the final becomes "replay the line, but bend around the cubes the camera reports." That's the robot we want to bring to the table this year, and for the first time it doesn't feel out of reach.

<br>

# Robot Construction Guide 

## Step 0: Print the 3D parts 

The part files can be found in the `3d-models` folder. We used and recommend the [BambuLab X1-Carbon](https://bambulab.com/en/x1) 3D printer, with the following settings:
 - Material: PLA-CF
 - Layer height: 0.2mm
 - Infill: 20%
 - Supports: Yes
 - Raft: No
 - Brim: Yes

## Step 1: Assemble the steering system 

1. Mount the `servo` on the `chassis` using 2 zip ties, make sure to cut the excess of the zip ties so it doesnt interfere with the steering arm.

2. Attach the `steering column` to the `servo` using a ⌀ 2mm metal rod, approximately 4mm in length.

3. Attach the `tie rod` to the `steering column` using a ⌀ 2mm metal rod, 10mm in length.

4. Hold the `steering knuckles` between the `chassis` and the `tie rod` and attach them with two ⌀ 2mm metal rod, 10mm in length.

6. Attach the `wheels` to the `steering knuckles` using 3mm d-shaft rods, approximately 15mm in length.

## Step 2: Assemble the powertrain 
1. Attach the `motor` to the `chassis` using the `motor bracket` and *M3* screws.

3. On the `motor`, attach the `24tooth spud gear`.

4. The differential should have 3 `Gear 12 Tooth Bevel`(<a href="https://www.bricklink.com/v2/catalog/catalogitem.page?P=6589#T=C">6589</a>) inside it. Hold the `differential` in the designated stop at the back of the chassis, attach it using lego `Axles 3L`. Insert the 2 `powertrain` parts on each `Axles 3L`. Insert a `15mm D-shaft rod` on each of the `powertrain` parts. Put the `wheels` on the `D-shaft rods`.

## Step 3: Attach the electronics  

1. Solder the components on the `pcb` according to the `electrical diagram`. We recommend using soldering sockets for the `Arduino` and the `motor driver` so that they can be easily removed if needed.

2. Place the `battery` in the place provided in the `chassis`.

3. Attach the `IMU` to the `chassis` using screws. Soulder a wire on the `IMU` on the `INT1` pin.

4. Screw the `pcb` to the `chassis` using *M3* screws, using `10 mm spacers` in the front.

5. Attach the `camera mount` to the `chassis` using screws.

6. Attach the `camera bracket` to the `camera mount` using screws.

5. Attach the `camera` to the `camera mount` using screws. Angle the `camera` slightly downwards so that it has a better view of the ground in front of the robot.

6. Connect all the wires according to the `electrical diagram`. The `camera` should be connected to the `Arduino` using the `UART` protocol. The `IMU` should be connected to the `Arduino` using the `I2C` protocol. The wires can be store bought, or you can make them yourself. We custom-made our wires to achieve the exact lengths needed and combined certain connections into single Dupont connectors—for example, the camera power, camera UART, and IMU I2C wires are each grouped within individual Dupont connectors.

7. (Optional) All the wires that are longer than needed can be wrapped arrond the `chassis` to make the robot look cleaner. You can use zip ties to secure the wires in place.

## Step 4: Upload the code 

1. Connect the `Arduino` to your computer using a USB cable.

2. Open the `Arduino IDE` and install the ESP32 board manager.

3. Upload the code to the `Arduino`.

4. Connect the `OpenMV Cam` to the your computer using a USB cable.

5. Open the `OpenMV IDE` and upload the code to the `OpenMV Cam`.

<br>

# Cost Report 

## Components 

| Component | Quantity | Cost per Unit (€) | Total (€) |
|---|---|---|---|
| 30:1 Micro Metal Gearmotor HPCB 12V | 1 | 21.00 | 21.00 |
| SparkFun Motor Driver - Dual TB6612FNG | 1 | 13.00 | 13.00 |
| Motor Servo MG90S | 1 | 4.00 | 4.00 |
| LiPo Battery (450mAh, 7.4V, 30C) | 1 | 9.00 | 9.00 |
| Arduino Nano ESP32 | 1 | 24.00 | 24.00 |
| Grove - 6-Axis Accelerometer & Gyroscope | 1 | 26.50 | 26.50 |
| OpenMV Cam RT1062 | 1 | 105.50 | 105.50 |
| PCB | 5 | 2 | 10.00 |
| Metal Rods (2mm diameter, various lengths)  | 6 | 0.50 | 3.00 |
| Pololu Wheels | 2 | 10.00 | 20.00 |
| Lego Gear 12 Tooth Bevel (6589) | 3 | 0.50 | 1.50 |
| Lego Axles 3L | 2 | 0.60 | 1.20 |

**Total for Components:** **€238.70**

---

## 3D Printing Costs 

- **Filament Used:**
  - Prototypes: 500g of PLA filament
  - Final Parts: 40g of PLA-CF filament
- **PLA-CF Filament Cost:** €32.00 per 1kg
- **PLA Filament Cost:** €25.00 per 1kg

| Filament Use | Weight (g) | Cost (€) |
|---|---|---|
| Prototypes | 500 | 12.50 |
| Final Parts | 40 | 1.28 |

**Total for 3D Printing:** **€27.56**

---

## Other Parts Tested 

- **Approximate Cost for Additional Parts Tested:** €150.00

---

## Tools and Equipment 

| Tool | Cost (€) |
|---|---|
| Bambu Lab X1 Carbon 3D Printer | 1,100.00 |
| Soldering Kit | 46.00 |
| Multimeter | 28.00 |
| Miscellaneous Tools (e.g., pliers) | 19.00 |

**Total for Tools and Equipment:** **€1,193.00**

---

## Summary of Costs 

| Category | Total (€) |
|---|---|
| Components | 238.70 |
| 3D Printing | 13.78 |
| Other Parts Tested | 150.00 |
| Tools and Equipment | 1,193.00  |
| Shipping Approximation | 100.00 |

**Grand Total:** **€1,695.48**

---

*Note: Costs are approximate and based on current exchange rates and market prices.*

<br>

# Randomizer 

To ensure the robot's ability to adapt to any course, we developed a randomizer that generates a random sequence of colors and positions for the cubes. You can find this web application at the following link: https://nerdvana.ro/wro-fe/

<br>

# Resources 

## Images 
<li> DC Motor - https://a.pololu-files.com/picture/0J10610.1200.jpg?204e9b873c23906503616db5c4950010
<li> MG90S Servo motor - https://www.robotistan.com/tower-pro-mg90s-micro-servo-motor-continuously-rotating-37080-99-B.jpg
<li> Sparkfun Motor Driver - https://cdn.sparkfun.com//assets/parts/1/2/4/8/2/14450a-01.jpg
<li> Arduino Nano ESP32 - https://ardushop.ro/7735-thickbox_default/arduino-nano-esp32-with-headers.jpg
<li> OpenMV Cam RT1062 - https://openmv.io/cdn/shop/files/cam-v5-front-hero-2-web_1000x.jpg?v=1699323324
<li> LiPo Battery - https://hpi-racing.ro/29739-medium_default/acumulator-lipo-gens-ace-g-tech-soaring-450mah-74v-30c-2s1p-cu-jst-syp.jpg
<li> Grove BMI088 Gyroscope - https://files.seeedstudio.com/wiki/Grove-6-Axis_Accelerometer-Gyroscope-BMI088/img/main.jpg
<li> Linear voltage regulator - https://m.media-amazon.com/images/I/71gro1yTESL._SL1500_.jpg
<li> Pololu Wheels - https://www.tme.eu/ro/details/pololu-1127/accesorii-pentru-robotica-si-rc/pololu/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

<br>

## Copyright 

```
MIT License

Permission is hereby granted, free of charge, to any person obtaining a copy of this software and associated documentation files (the "Software"), to deal in the Software without restriction, including without limitation the rights to use, copy, modify, merge, publish, distribute, sublicense, and/or sell copies of the Software, and to permit persons to whom the Software is furnished to do so, subject to the following conditions:

The above copyright notice and this permission notice shall be included in all copies or substantial portions of the Software.

THE SOFTWARE IS PROVIDED "AS IS", WITHOUT WARRANTY OF ANY KIND, EXPRESS OR IMPLIED, INCLUDING BUT NOT LIMITED TO THE WARRANTIES OF MERCHANTABILITY, FITNESS FOR A PARTICULAR PURPOSE AND NONINFRINGEMENT. IN NO EVENT SHALL THE AUTHORS OR COPYRIGHT HOLDERS BE LIABLE FOR ANY CLAIM, DAMAGES OR OTHER LIABILITY, WHETHER IN AN ACTION OF CONTRACT, TORT OR OTHERWISE, ARISING FROM, OUT OF OR IN CONNECTION WITH THE SOFTWARE OR THE USE OR OTHER DEALINGS IN THE SOFTWARE.

© 2026 Nerdvana Romania
```

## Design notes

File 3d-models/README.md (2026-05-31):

# 3D Models

This folder contains all 3D models used in the project.

## Structure

- `custom/` – Models designed by the team specifically for this robot (e.g., chassis, mounts, holders).
- `downloaded/` – External models sourced from the internet (e.g., standard connectors, components).

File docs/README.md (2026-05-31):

# Documentation

This folder contains internal guidelines, project checklists, and other supporting materials for the development of the robot.

All content here is intended for use by the project team only.

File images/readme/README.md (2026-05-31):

# Images for README

Visuals used in `README.md` (diagrams, flowcharts, UI elements, etc.).

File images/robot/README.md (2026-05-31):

# Robot Photos

Photos of the robot at various stages (top view, side view, final assembly, etc.).

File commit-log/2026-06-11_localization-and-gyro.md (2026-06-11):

# On-board localization and drift-free gyro

- **Date:** 2026-06-11
- **Author:** Bălan T.
- **Commit hash (optional):**
- **Summary:** Reworked the race firmware around this season's software. The gyro now samples at 1000 Hz with a continuous zero-rate update so the heading no longer drifts over a run. Added a localization module (`6_localization.ino`) that keeps a live (x, y) position on the mat by dead reckoning and records the line we drive, with corner marks coming from the camera. The camera now loads its tuned colour thresholds from `thresholds.json` at boot and tags each corner with an `M` message. Named this year's robot M.D.S in the docs.
- **Reason:** The one-time boot drift measurement was letting the heading walk off by a couple of degrees after a few laps, and we wanted the robot to know where it is on the mat, not just which way it points, so we can drive a remembered line instead of reacting corner by corner.
- **Impact:** Affects `1_gyro.ino`, `2_motors.ino`, `5_loop.ino`, `v5.ino` and adds `6_localization.ino`; camera `v5_camera.py`. No change to the proven chassis. Compiles clean for the Arduino Nano ESP32.
- **Testing status:** Partially tested (gyro and odometry verified on the bench; replaying the recorded line and the localization-based parking are still being tuned).

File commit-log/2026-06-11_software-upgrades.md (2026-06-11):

# Document this season's software work

- **Date:** 2026-06-11
- **Author:** Bălan T.
- **Summary:** Added Andrei to the team and documented this year's software upgrades in the README: the WiFi pit dashboard, the drift-free 1000 Hz gyro with continuous zero-rate update, the self-calibrating steering center, and the start of our own dead-reckoning localization and route memory.
- **Reason:** Most of our effort this season went into software rather than the mechanical build, and none of it was written up yet. The documentation needed to reflect what the robot actually does now.
- **Impact:** Documentation only, no behavior change. New team member entry, new "What We Changed This Year" section, updated table of contents.
- **Testing status:** Fully tested (everything documented runs on the bench; route replay and the new parking approach are noted as work in progress).

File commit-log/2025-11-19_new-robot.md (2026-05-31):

# New Robot Design and Integration
- **Date:** 2025-11-19
- **Author:** Priboi M.
- **Summary:** Added new robot design files and integrated them into the main project.
- **Reason:** To enhance the robot's capabilities and improve performance for upcoming competition.
- **Impact:** Affects mechanical design. Much smaller build. Speed and maneuverability upgraded. Steering system now uses Ackermann geometry and is more responsive and stable. Now uses a PCB for better wiring management.
- **Testing status:** Fully tested

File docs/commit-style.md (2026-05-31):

# Internal Contribution Guidelines

This file outlines the commit and documentation rules to be followed by the team.

---

## Commit Message Format

We use semantic commit messages for clarity and traceability. Every commit must follow this structure:

```
<type>: <short summary>

<optional longer explanation>
```

### Accepted Types
- `feat` – New feature (hardware, software, config)
- `fix` – Bug fix or issue resolution
- `refactor` – Code restructuring without behavior changes
- `docs` – Edits to documentation (README, logs, etc.)
- `test` – Add or modify test cases or simulation scenarios
- `chore` – Maintenance tasks (clean-up, config files)
- `build` – CAD, electrical, mechanical file updates

### Examples
```
feat: integrate IMU calibration script

docs: document wiring changes in chassis v3

fix: correct LIDAR angle offset in obstacle detection
```

Guidelines:
- Write in English
- Summary line should be under 72 characters
- Use imperative tone (e.g., "add", "fix", not "added" or "fixed")
- One commit per logical change

---

## Commit Log Documentation

For significant changes, a corresponding Markdown file should be created in `commit-log/` using this structure:

**File name format:** `YYYY-MM-DD_short-description.md`

**Template:**
```
# [Short Title]

- **Date:** 2025-MM-DD
- **Author:** [Initials or name]
- **Commit hash (optional):** abc123
- **Summary:** What was changed
- **Reason:** Why it was necessary
- **Impact:** Effects on other modules or subsystems
- **Testing status:** one of the following
    - Fully tested
    - Partially tested
    - Not tested
```

This helps maintain a detailed engineering log and supports final documentation requirements.

---

## Structure and Standards

- Keep all diagrams, CAD, and hardware documentation in their assigned folders.
- Write all documentation in clear, technical English.
- Maintain consistent file naming across all assets.
- Avoid merging large, unrelated changes into a single commit.

---

This file is maintained for the exclusive use of the team and reflects internal development standards.

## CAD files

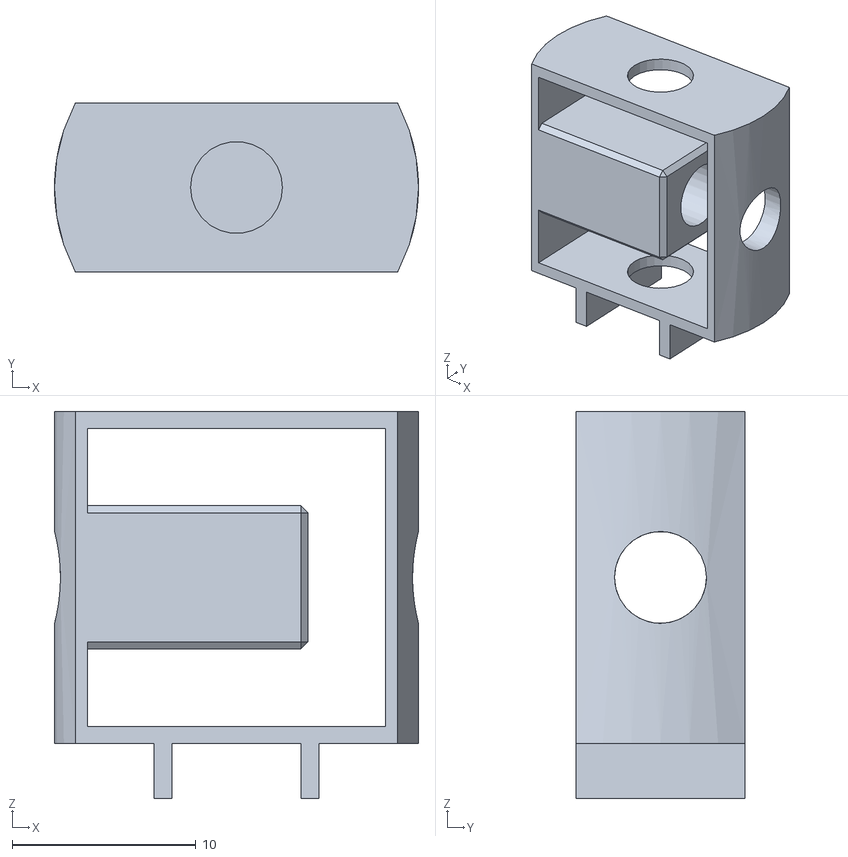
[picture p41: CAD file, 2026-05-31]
3d-models/downloaded/lego micro diff housing v2.obj
19.8 x 9.20 x 21.0

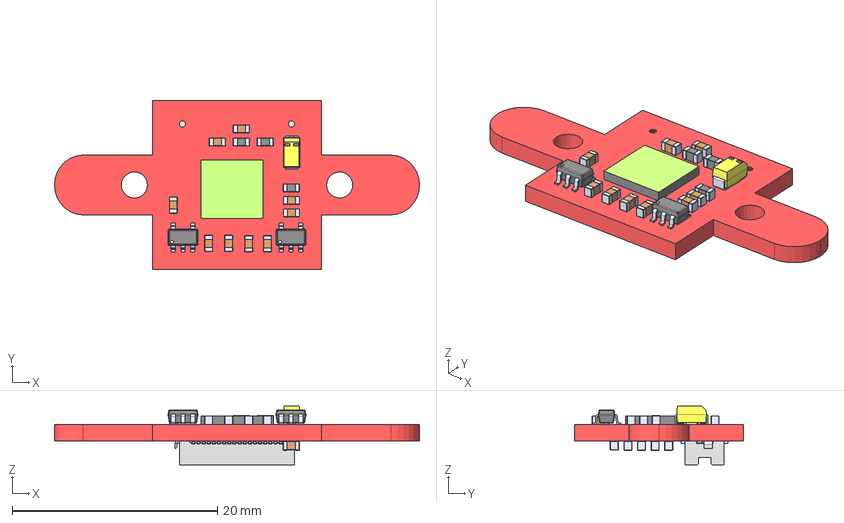
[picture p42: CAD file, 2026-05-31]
3d-models/downloaded/openmv-cam-rt1062-1.snapshot.7/ov5640.step
35.6 x 16.5 x 5.70 mm
DF1236
CAP pt1 uF 0603 x 7
CAP 10 uF 0603 x 3
Ferrite Bead 0603
CAP 1 uF 0603 x 6
Tantalum Capacitors 3216 47uf
MOSFET SOT23_5 x 2
OV5640

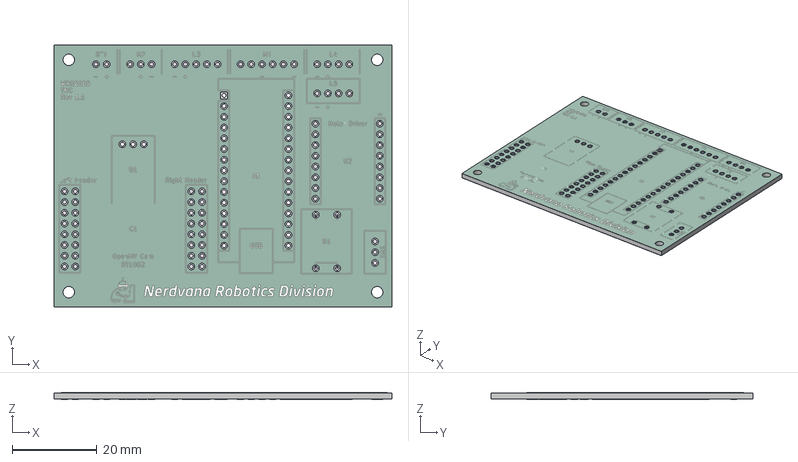
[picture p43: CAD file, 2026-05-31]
build-diagrams/pcb/pcb.step
80.0 x 62.0 x 1.66 mm
pcb_copper
pcb_pad
pcb_silkscreen
pcb_soldermask
pcb_PCB

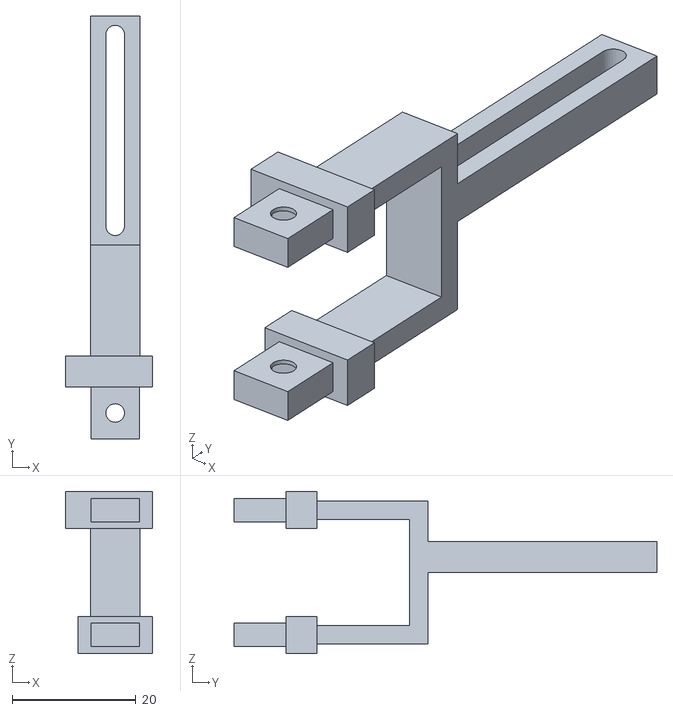
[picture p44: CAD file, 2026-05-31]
3d-models/Camera_Mount.stl
14.0 x 68.4 x 26.2

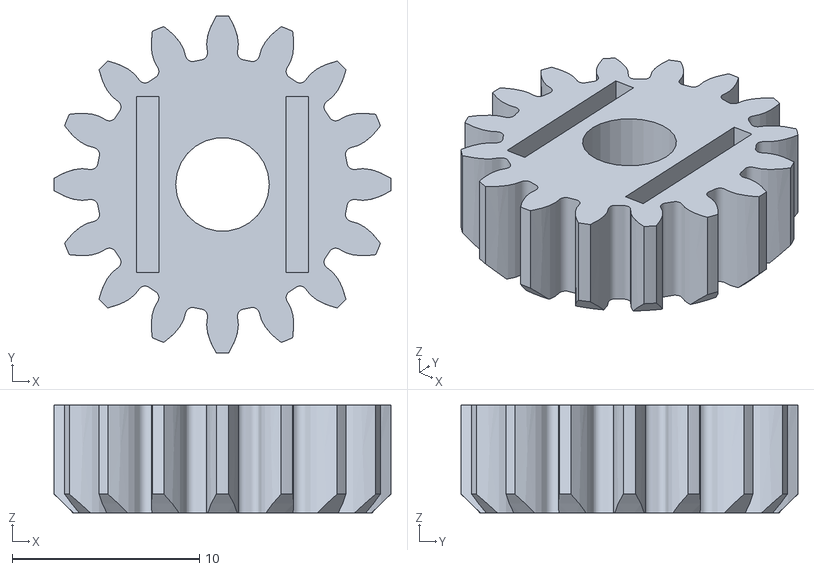
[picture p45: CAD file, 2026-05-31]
3d-models/downloaded/lego micro diff housing gear 16 teeth v2.obj
18.0 x 18.0 x 5.75

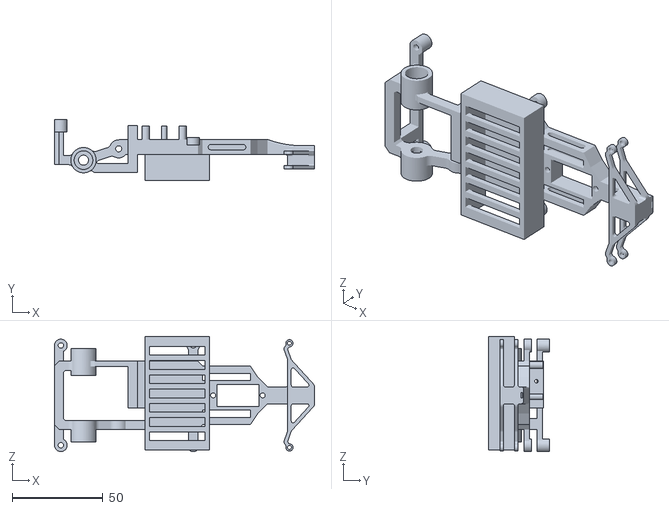
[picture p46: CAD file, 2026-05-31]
3d-models/Chassis.stl
143.3 x 33.8 x 63.5

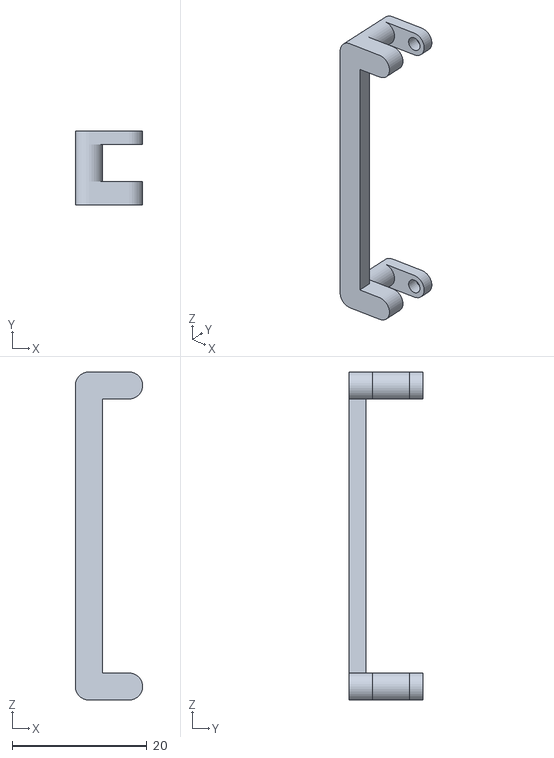
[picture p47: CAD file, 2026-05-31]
3d-models/Tie_Rod.stl
10.0 x 11.0 x 48.7

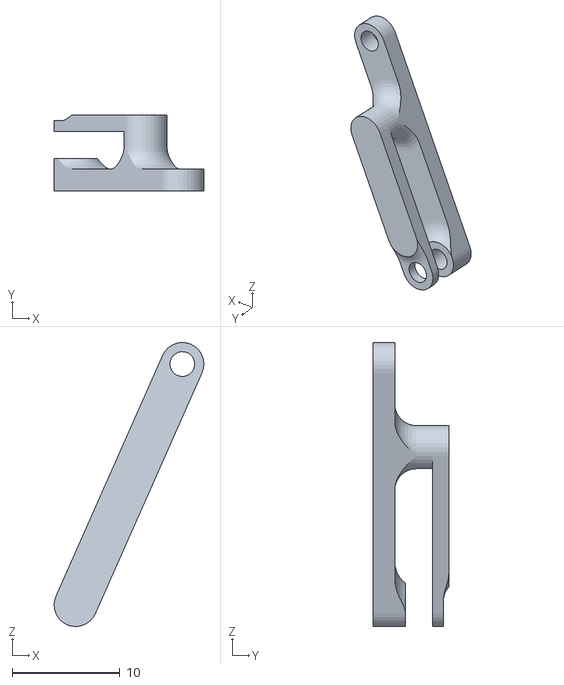
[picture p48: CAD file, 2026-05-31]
3d-models/Steering_Column.stl
13.9 x 7.00 x 26.3

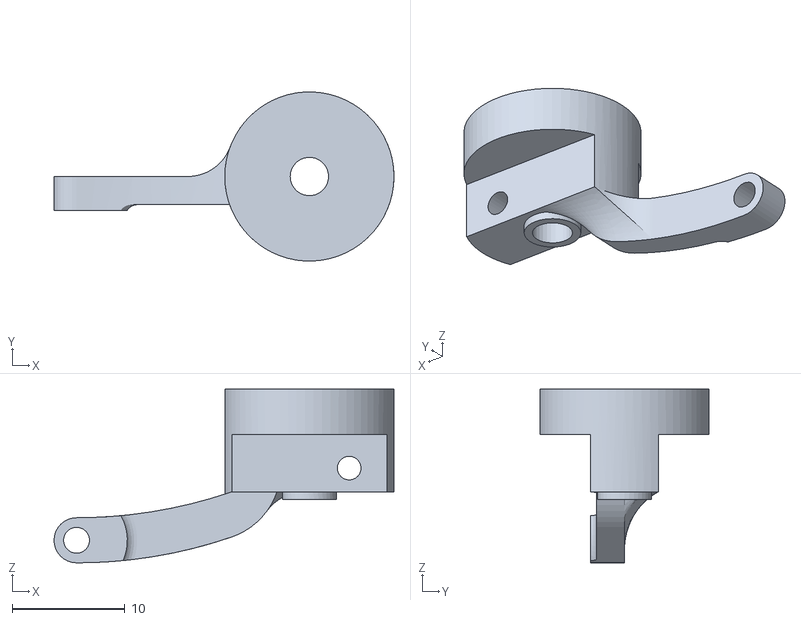
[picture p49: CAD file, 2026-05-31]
3d-models/Steering_Knuckle.stl
30.1 x 15.0 x 15.4

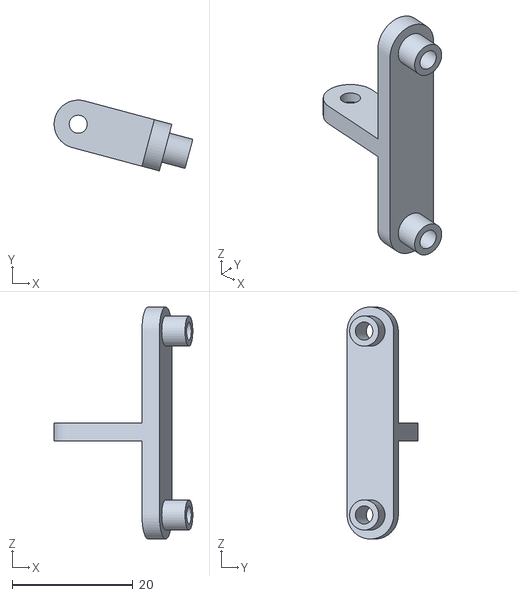
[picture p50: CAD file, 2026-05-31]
3d-models/Camera_Bracket.stl
23.0 x 11.7 x 38.5

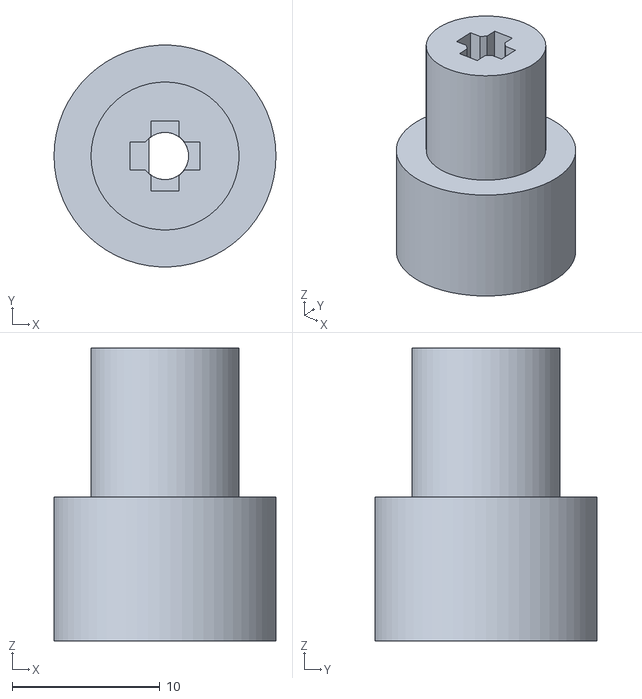
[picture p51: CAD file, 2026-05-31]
3d-models/Powertrain.stl
15.0 x 15.0 x 19.8

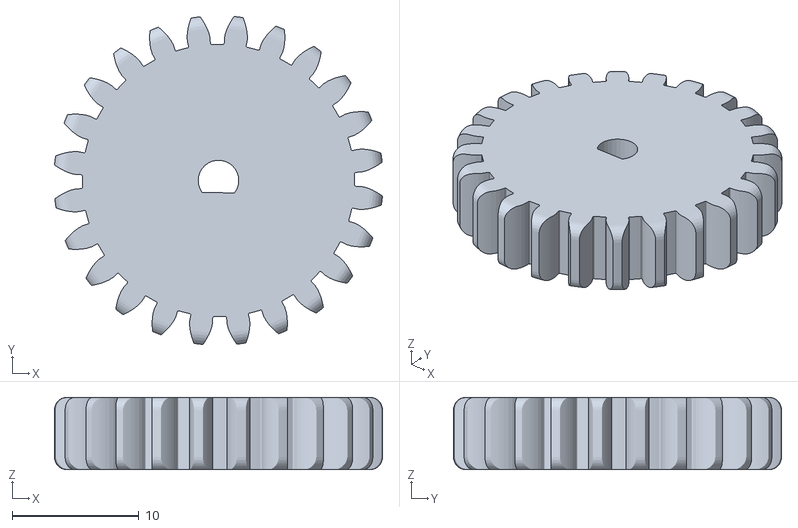
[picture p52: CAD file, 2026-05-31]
3d-models/24Teeth_Spur_Gear.stl
25.9 x 25.9 x 5.70

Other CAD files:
3d-models/pcb.stl

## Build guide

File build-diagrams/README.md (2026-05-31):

# Build Diagrams

Includes wiring diagrams, schematics, PCB layouts, and block diagrams related to electrical or logical design.

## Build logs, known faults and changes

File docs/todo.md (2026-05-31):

# To-Do List

This file tracks outstanding tasks for robot development, documentation, and submission preparation. It should be maintained and kept up to date throughout the project.

---

## Major Milestones

- [x] Finalize new chassis design
- [x] Prepare or print all components and assemble robot
- [x] Finalize the open round code
- [x] Finalize the obstacle round code
- [x] Pass all randomized challenge scenarios in testing
- [x] Prepare final documentation and submission materials

---

## Development Tasks

- [x] Incorporate new camera with last year's robot
- [x] Write updated documentation for new camera

---

## Documentation and Git

- [x] Create repo and define structure
- [x] Write new `README.md`
- [x] Include wiring diagrams and hardware layout in `build/`

---

## Submission Checklist

- [x] Record and edit final run video
- [x] Confirm video is uploaded and accessible
- [x] Ensure source code is complete and readable
- [x] Submit repo for national
- [x] Submit repo for international

---

Last updated: 2025-11-19

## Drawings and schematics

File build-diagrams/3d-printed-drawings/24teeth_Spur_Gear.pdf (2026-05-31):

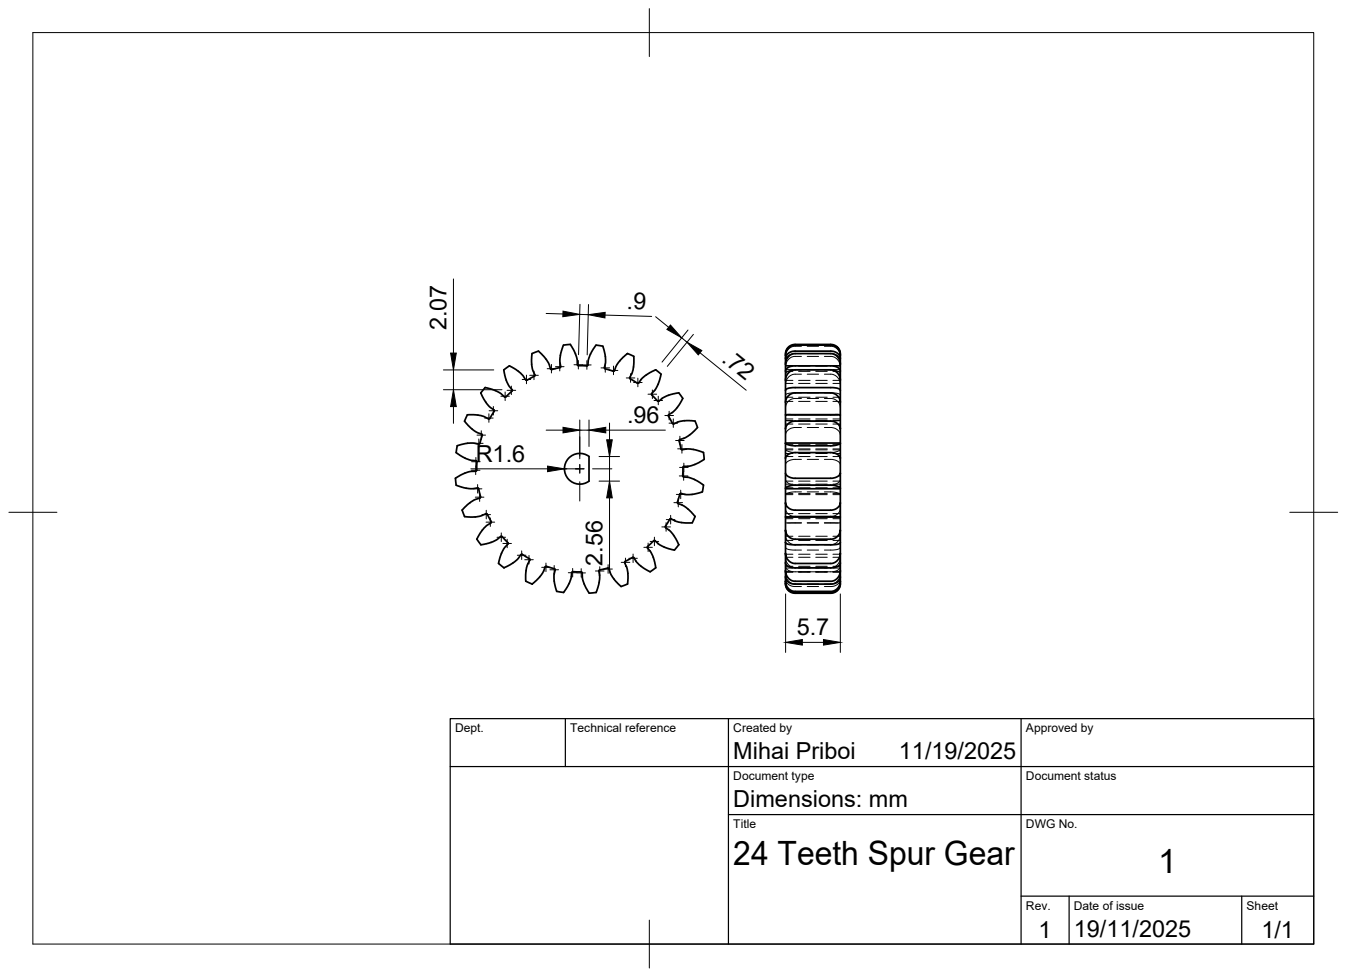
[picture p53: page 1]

Dept. | Technical reference | Created by Mihai Priboi 11/19/2025 | Approved by

Document type Dimensions: mm | Document status

Title 24 Teeth Spur Gear | DWG No. 1

Rev. 1 | Date of issue 19/11/2025 | Sheet 1/1

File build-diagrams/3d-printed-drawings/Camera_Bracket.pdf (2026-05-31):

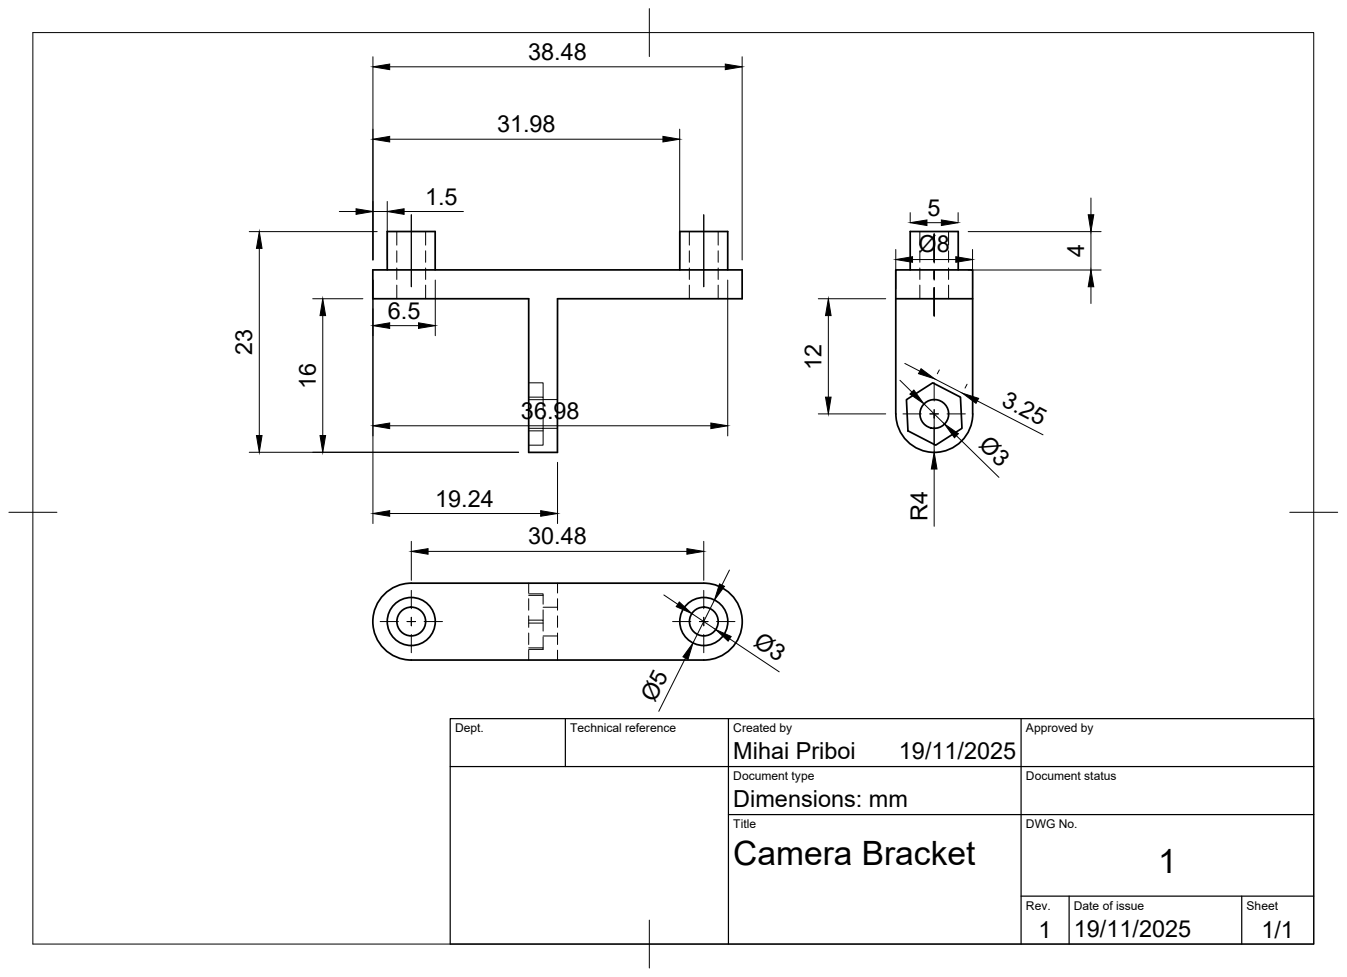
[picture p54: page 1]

Dept. | Technical reference | Created by Mihai Priboi 19/11/2025 | Approved by

Document type Dimensions: mm | Document status

Title Camera Bracket | DWG No. 1

Rev. 1 | Date of issue 19/11/2025 | Sheet 1/1

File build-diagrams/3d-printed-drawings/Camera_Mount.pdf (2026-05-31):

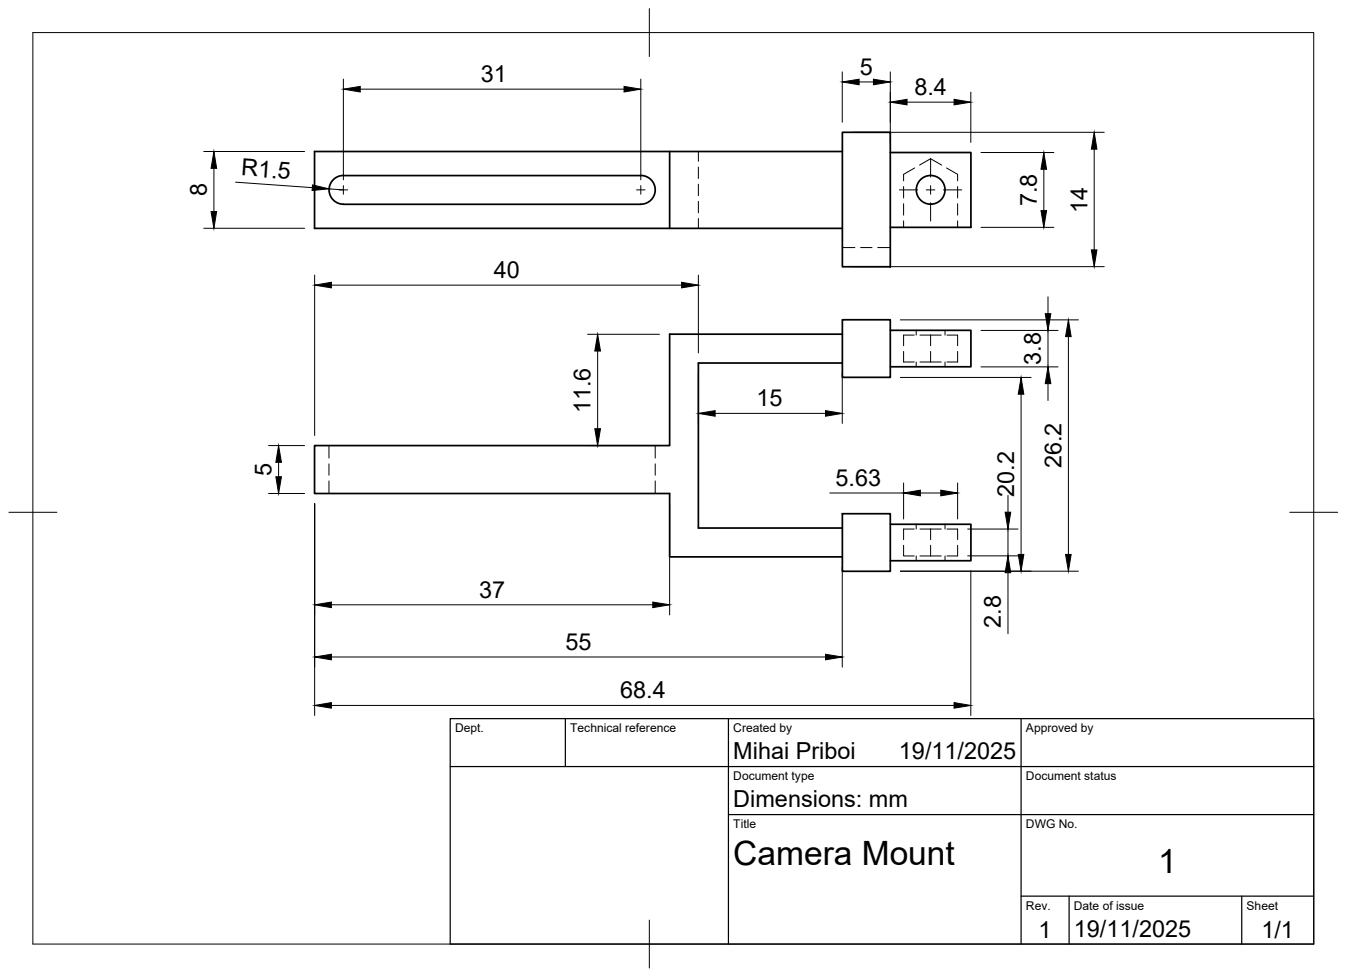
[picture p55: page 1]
Mihai Priboi

Dept. | Technical reference | Created by 19/11/2025 | Approved by

Document type Dimensions: mm | Document status

Title Camera Mount | DWG No. 1

Rev. 1 | Date of issue 19/11/2025 | Sheet 1/1

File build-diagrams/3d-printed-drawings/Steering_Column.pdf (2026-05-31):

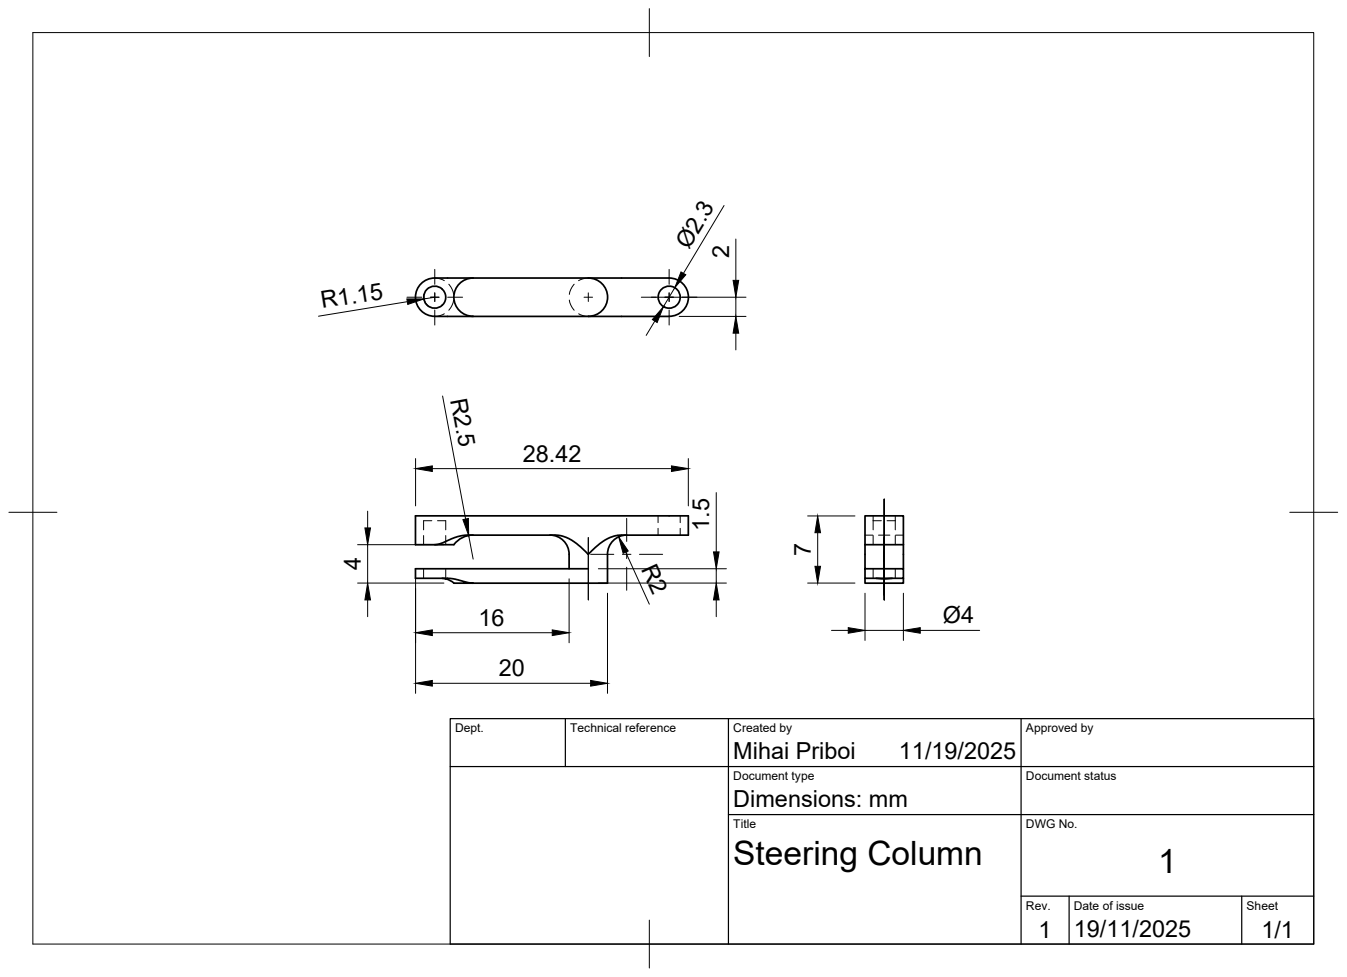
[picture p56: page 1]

Dept. | Technical reference | Created by Mihai Priboi 11/19/2025 | Approved by

Document type Dimensions: mm | Document status

Title Steering Column | DWG No. 1

Rev. 1 | Date of issue 19/11/2025 | Sheet 1/1

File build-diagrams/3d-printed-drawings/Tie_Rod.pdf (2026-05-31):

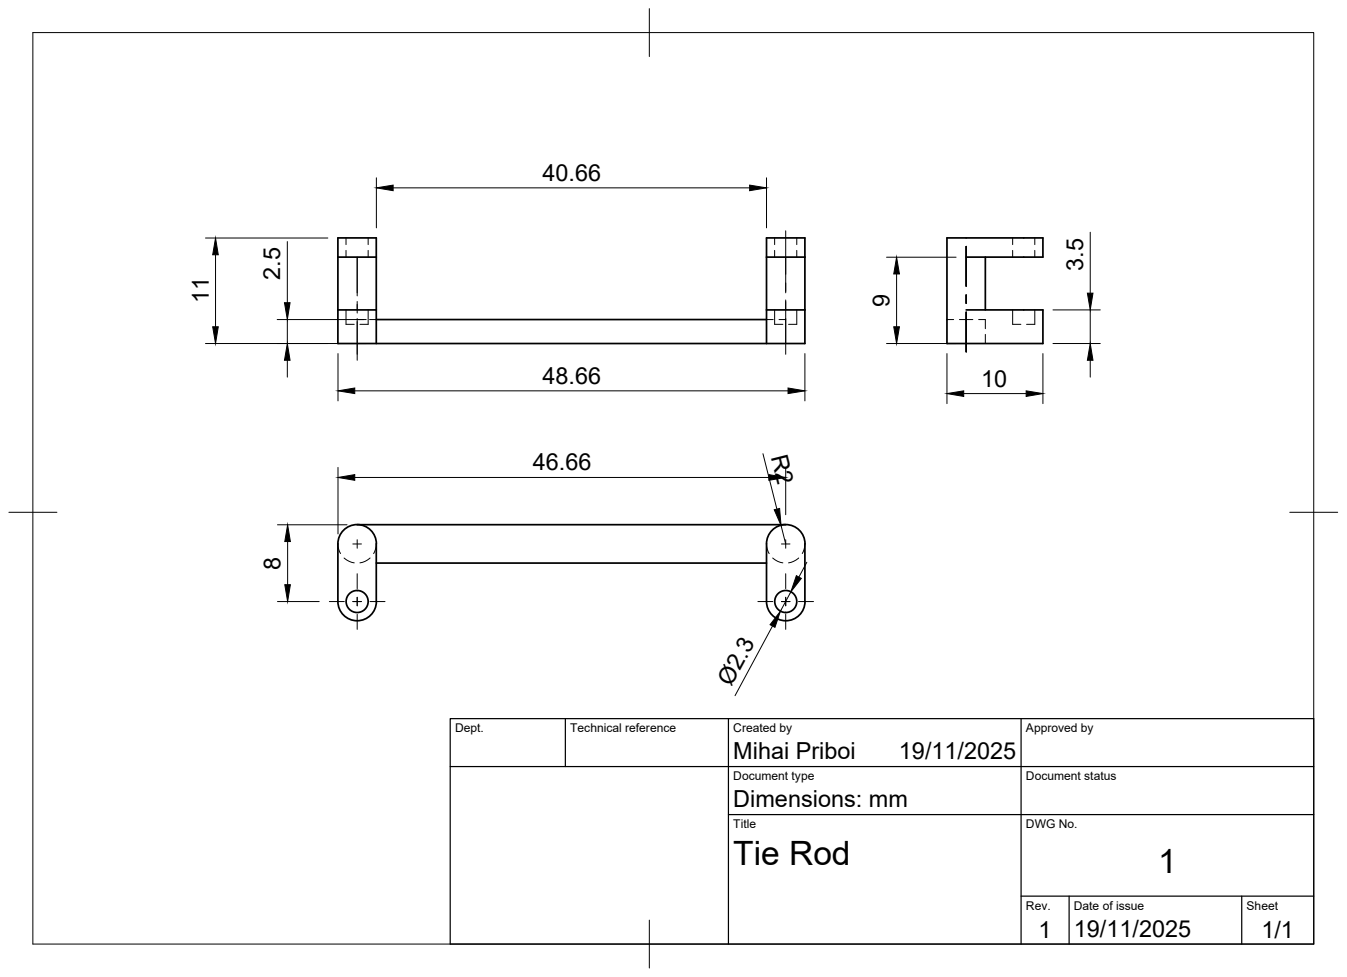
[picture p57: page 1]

Dept. | Technical reference | Created by Mihai Priboi 19/11/2025 | Approved by

Document type Dimensions: mm | Document status

Title Tie Rod | DWG No. 1

Rev. 1 | Date of issue 19/11/2025 | Sheet 1/1

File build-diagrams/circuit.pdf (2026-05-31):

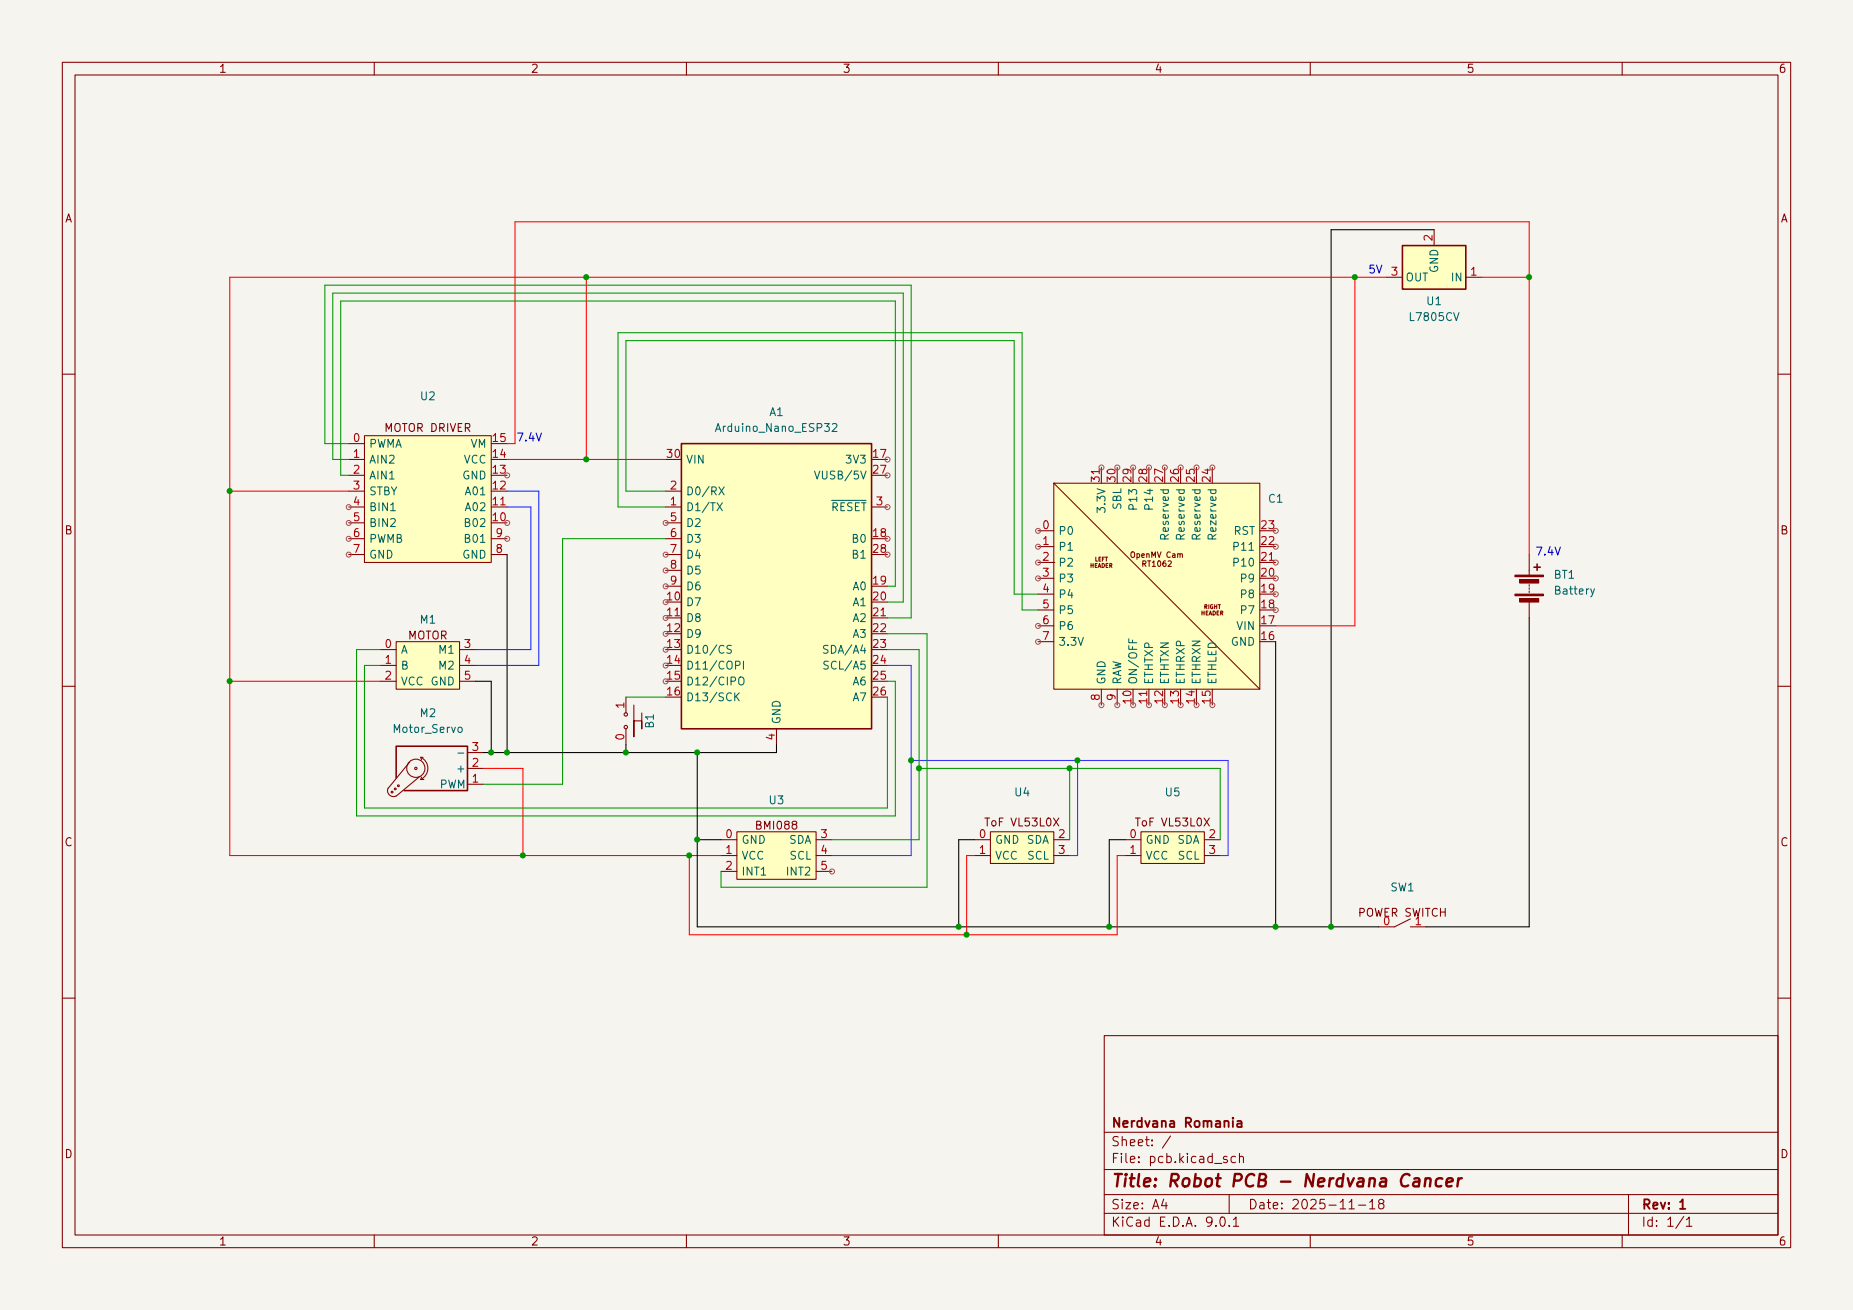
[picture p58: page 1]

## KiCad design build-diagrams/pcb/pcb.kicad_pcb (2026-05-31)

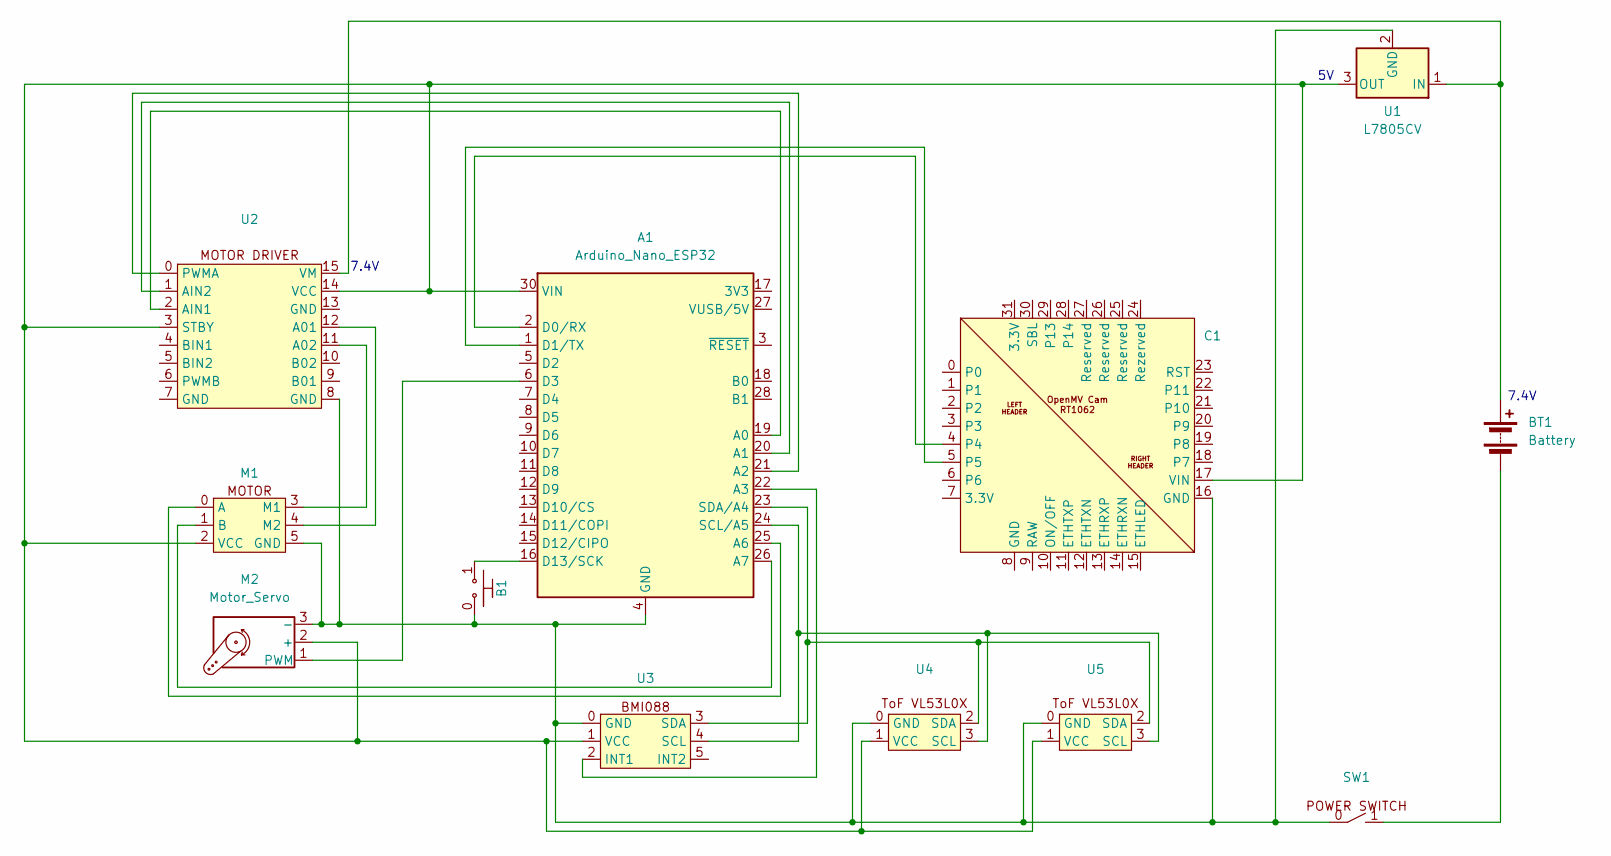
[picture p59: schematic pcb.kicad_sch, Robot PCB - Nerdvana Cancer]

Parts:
A1: Arduino_Nano_ESP32; Arduino_Nano
B1: Start Button
BT1: Battery
C1: OPENMV_H7
M1: DC_GEARMOTOR
M2: Motor_Servo; Servo Motor
SW1: Switch
U1: L7805CV
U2: Motor Driver
U3: BMI088
U4, U5: ToF_VL53L0X

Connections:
unnamed: A1.19 (A0), U2.2 (AIN1)
unnamed: A1.20 (A1), U2.1 (AIN2)
unnamed: A1.21 (A2), U2.0 (PWMA)
unnamed: A1.22 (A3), U3.2 (INT1)
unnamed: A1.25 (A6), M1.0 (A)
unnamed: A1.26 (A7), M1.1 (B)
unnamed: A1.2 (D0/RX), C1.4
unnamed: A1.1 (D1/TX), C1.5
unnamed: A1.6 (D3), M2.1 (PWM)
unnamed: A1.16 (D13/SCK), B1.1
unnamed: A1.24 (SCL/A5), U3.4 (SCL), U4.3 (SCL), U5.3 (SCL)
unnamed: A1.23 (SDA/A4), U3.3 (SDA), U4.2 (SDA), U5.2 (SDA)
unnamed: A1.30 (VIN), C1.17 (VIN), M1.2 (VCC), M2.2 (+), U1.3 (OUT), U2.3 (STBY), U2.14 (VCC), U3.1 (VCC), U4.1 (VCC), U5.1 (VCC)
unnamed: BT1.1 (+), U1.1 (IN), U2.15 (VM)
unnamed: BT1.2 (-), SW1.1
unnamed: A1.4 (GND), A1.29 (GND), B1.0, C1.16 (GND), M1.5 (GND), M2.3 (-), SW1.0, U1.2 (GND), U2.8 (GND), U3.0 (GND), U4.0 (GND), U5.0 (GND)
unnamed: M1.3 (M1), U2.11 (A02)
unnamed: M1.4 (M2), U2.12 (A01)

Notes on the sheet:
7.4V

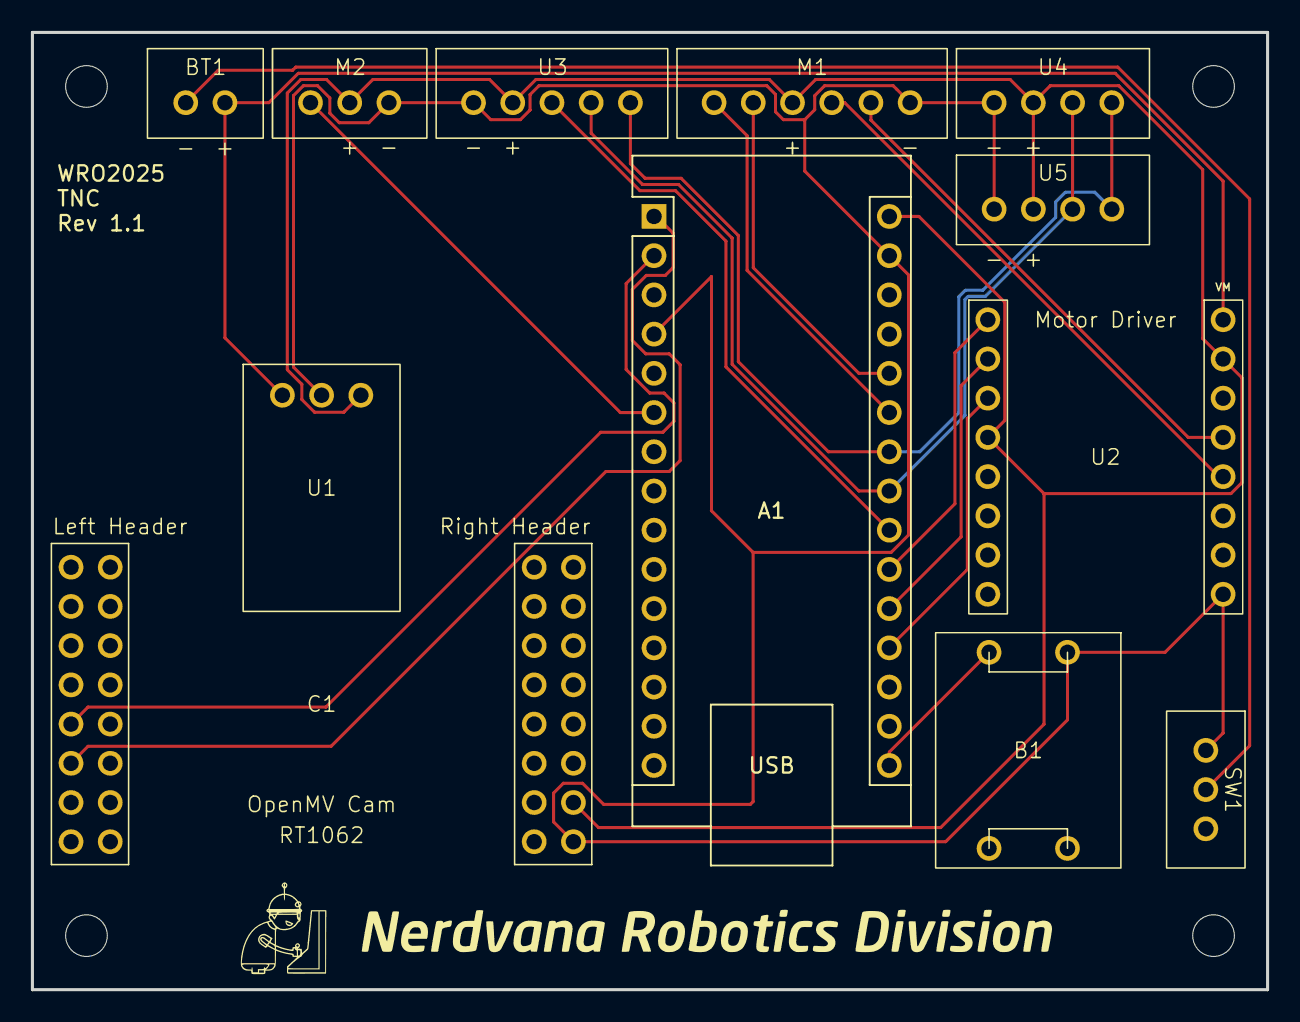
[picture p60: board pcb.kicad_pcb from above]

Board: 2 copper layers, 80.0 x 62.0 mm, 12 parts (0 on the bottom side), 18 nets.

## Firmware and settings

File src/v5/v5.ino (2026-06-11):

#include <math.h>
#include <Encoder.h>
#include <ESP32Servo.h>
#include <Wire.h>
#include "BMI088.h"

#define FINAL true

// -----Button and Debug led-----
#define BTN_PIN A3
#define DEBUG_LED D12

void setup() {
  setup_function();
}

bool is_running = false;

uint32_t last_rotate = 0, time_elapsed = 0;

void loop() {
  int is_start_btn_on = digitalRead(BTN_PIN); // wait for the button to be pressed
  read_gyro(false); // flush the data
  flush_messages();
  if (!is_running && is_start_btn_on == LOW) { // if we press the button and the program isn't running
    is_running = true; // start the program
    
    digitalWrite(LED_BUILTIN, LOW);
    digitalWrite(DEBUG_LED, LOW); // turn off the debugging leds

    // custom_delay(3000);

    localization_reset(); // start the map fresh from the start tile
    last_rotate = millis(); // initialize times
    // time_elapsed = millis();
    // freq = 0;
  }
  if (is_running) { // if the program is running, execute one iteration of the loop function
    loop_function();
  }
}

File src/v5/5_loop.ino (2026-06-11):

// -----Units of measurement-----
// The velocities are on a -100 to 100 scale
// The distances are in cm
// The time is in ms
// The angles are in degrees

// -----Cases-----
#define PID 0
#define FOLLOW_CUBE 1
#define AFTER_CUBE 2
#define STOP_BEFORE_FIND_PARKING 3
#define POSITION_BEFORE_FIND_PARKING 4
#define FIND_PARKING 5
#define POSITION_FOR_PARK 6
#define PARK 7
#define STOP_FINAL 8
#define STOP_QUALI 9
#define STRAIGHTEN_FOR_PARKING 10

int CASE = PID;

// -----Angles-----
#define CORRECTION_ANGLE 50
#define AVOIDANCE_ANGLE 55
#define TURNAROUND_ANGLE 50
#define PARKING_GYRO_OFFSET 1.25
double follow_cube_angle = 0;

// -----Distances-----
#define CORNER_DISTANCE_FINAL 10
#define CORNER_DISTANCE_QUALI 38 // maybe 40 if the battery is overcharged
#define CORNER_DISTANCE_PARKING 46
#define AFTER_CUBE_DISTANCE 12

// -----Velocities-----
#define MOTOR_SPEED 100
#define PARKING_SPEED 70

// -----Times-----
#define TURNAROUND_DELAY 1500
#define FIRST_STOP_DELAY 1500
#define FOLLOW_CUBE_DEAD_TIME 250
#define PASS_CUBE_DELAY 350

// -----Logic-----
int turn_direction = 0;
int delay_walls = 250;
int cube_last = 0;
int turns = 0;
long last_follow_cube = 0;
long last_cube_time = 0;
int is_front = 0;
int no_cubes = 0;
int before_cube = 0;
int first_cube = 0;

int before_side_last_cube = 0; // the color of the last cube from the side that comes before the starting side (0 if non-existent)
bool turned = false; // if we did the turnaround or not

bool completed_run = false;

// -----Debug-----
long last_gyro_read = 0;
int freq = 0;

// hardcoded sequence that avoids a cube
void pass_cube(int cube_last) {
  read_gyro(false);
  double angle_addition = 0;
  double start_angle = gx;
  double err = abs(current_angle_gyro - start_angle);

  // if (err >= 50) { // if we're really crooked, substract a given value so that we don't overcompensate
  //   angle_addition -= 10;
  // } 
  // else {
  //   angle_addition -= max(err / 2.75, 0.0); // if we're crooked, dinamically adjust the avoidance angle so that we don't overshoot
  // }
  // if (cube_last == -1)
  //   angle_addition += 15;
  // else
  //   angle_addition -= 3;
  move_until_angle(MOTOR_SPEED, start_angle - cube_last * (AVOIDANCE_ANGLE + angle_addition)); // steer away from the cube
  move_cm_gyro(AFTER_CUBE_DISTANCE, MOTOR_SPEED, start_angle - cube_last * (AVOIDANCE_ANGLE + angle_addition));

  last_cube_time = millis();
  CASE = AFTER_CUBE;
}

// hardcoded sequence that turns around
// we need the last passed cube so that we know which way we take the turn so that we don't hit anything
void turn_around(int cube_last) {
  read_gyro(false);
  double start_angle = gx;
  move_until_angle(MOTOR_SPEED, start_angle - cube_last * 57);
  move_until_angle(MOTOR_SPEED, current_angle_gyro + cube_last * 200);
  current_angle_gyro += cube_last * 180;
  turn_direction *= -1;
  turned = true;
  CASE = PID;
}

// function that parses a command and executes it
void execute(String cmd) {
  if (!valid_command(cmd))
    return;

  if (cmd[0] == 'M') { // the camera tagged a corner -> pin it on our map
    mark_corner();
    return;
  }

  // the following sequence gets the number from the command (if available)
  int pos = 0, sign = 1;
  if (cmd[pos] == 'r' || cmd[pos] == 'g')
    pos++;
  // manually going over the signs since the .toDouble function wouldn't parse them on its own
  if (cmd[pos] == '+')
    sign = 1, pos++;
  else if (cmd[pos] == '-')
    sign = -1, pos++;
  double val = cmd.substring(pos).toDouble();

  if (FINAL) { // if we're in the final round
    if (CASE == FIND_PARKING && cmd[0] == 'P') { // if we're searching for the parking spot and we find it
      CASE = POSITION_FOR_PARK; // park the robot
      return;
    }

    if (cmd[0] == 'P') // if we see the parking slot, but we didn't finish the obstacle round we ignore it
      return;

    // if(cmd[0] == 'S') {
    //   if(cmd[1] == 'L')
    //     move_until_angle(MOTOR_SPEED, current_angle_gyro - 20); // straighten ourselves
    //   else
    //     move_until_angle(MOTOR_SPEED, current_angle_gyro + 20); // straighten ourselves
    // }

    if (CASE == STRAIGHTEN_FOR_PARKING && cmd[0] == 'W') {
      CASE = FIND_PARKING;
      current_angle_gyro += turn_direction * 90; // update the goal angle for the next sequence
      turns++; // increase the number of turns made
      delay_walls = 2300; // larger delay for every turn except the first one
      // as we may have the starting position close to the first turn
      last_rotate = millis(); // update the last time we turned
      return;
    }

    if (CASE == POSITION_BEFORE_FIND_PARKING && cmd[0] == 'W') { // if we're positioning ourselves close to the wall and we're in its proximity
      CASE = STRAIGHTEN_FOR_PARKING; // start searching for the parking lot
      return;
    }

    if (CASE == PARK && (cmd[0] == 'W' && cmd[1] == 'P')) { // if we're positioning ourselves close to the wall and we're in its proximity
      move_cm_gyro(8, PARKING_SPEED, current_angle_gyro - turn_direction * 90); // position ourselves closer
      CASE = STOP_FINAL; // we finished the parking, stop
      return;
    }

    if (cmd[0] == 'W') // if we see the outer wall, but we don't need it we ignore it
      return;

    if (CASE != FIND_PARKING && CASE != POSITION_BEFORE_FIND_PARKING && CASE != PARK) {
      if ((cmd[0] == 'R' || cmd[0] == 'G') && millis() - last_cube_time >= PASS_CUBE_DELAY) { // if we're in the proximity of a cube
        if (turns == 7)
          before_side_last_cube = cube_last; // remember the last passed cube (excluding this one)
        if (cmd[0] == 'R') { // we determine the direction in which we avoid the cube and remember its color
          cube_last = 1;
        }
        else {
          cube_last = -1;
        }

        if(turns == 0)
          is_front = 1;

        if(turns == 4) {
          no_cubes++;
          if(first_cube == 0)
            first_cube = cube_last;
        }

        if(turns == 7) {
          before_cube = cube_last;
        }

        if(turns == 8) {
          if(is_front == 0)
            before_cube = cube_last;
          else if(no_cubes == 2) {
            before_cube = first_cube;
          }
        } 

        if (turns == 8 && !turned) // if we have are in the position to turn around, the cube is red and we haven't turned around already
          turn_around(cube_last);
        else 
          pass_cube(cube_last);
        return;
      }
      if (cmd[0] == 'r' || cmd[0] == 'g') { // if we see a cube but we're not close enough to avoid it
        follow_cube_angle = val * sign;
        CASE = FOLLOW_CUBE;
        last_follow_cube = millis();
        return;
      }
    }
  }
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

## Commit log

2026-05-31 fork of last year's repo
    [24Teeth_Spur_Gear.stl, Camera_Bracket.stl, Camera_Mount.stl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]
2026-06-02 Increase minimum turn radius from 150mm to 175mm
2026-06-11 docs: add Andrei to the team and document this season's software
    Write up the work that went into the robot this year: the WiFi pit dashboard, the drift-free 1000 Hz gyro with continuous zero-rate update, the self-calibrating steering center, and our own dead-reckoning localization and route memory. Updates the team section and the table of contents.
2026-06-11 feat: add on-board localization and drift-free gyro
    Move the heading to a 1000 Hz sample with a continuous zero-rate update so it stops drifting over a run, and add a dead-reckoning localization module that tracks (x, y) on the mat and records the driven line, with corner marks from the camera. The camera now loads tuned thresholds from thresholds.json at boot. Documented this season's work and named the robot M.D.S.
    [1_gyro.ino, 2_motors.ino, 5_loop.ino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]
